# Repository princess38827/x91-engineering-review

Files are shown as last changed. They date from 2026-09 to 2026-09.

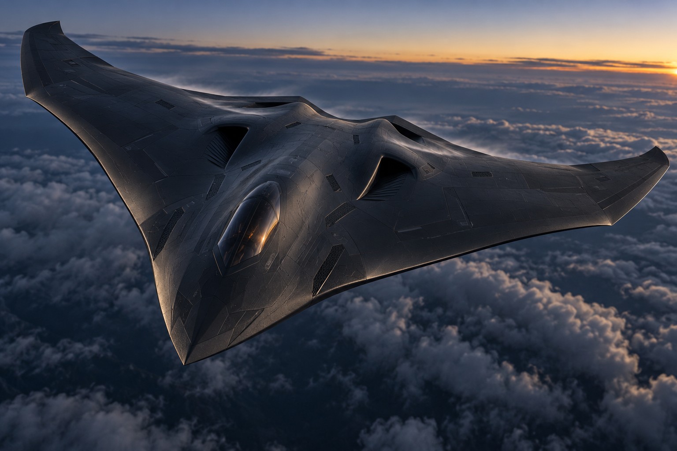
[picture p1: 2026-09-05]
assets/x91-concept-reference.jpg

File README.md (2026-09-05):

# X-91 Engineering Review Portal

Static Vercel portal and complete source package for the X-91 civilian, non-weaponized flight demonstrator approval candidate.

## Status

This repository is **not a fabrication or flight authorization**. All flight-control approval requirements remain open until supported by measured evidence and signed by qualified reviewers.

## Local preview

```bash
python3 -m http.server 8080
```

Open `http://localhost:8080`.

## Verification

```bash
PYTHONPATH=source python3 -m unittest discover -s source/analysis -v
python3 -m json.tool source/config.json >/dev/null
```

The `source/` directory contains the complete reproducible engineering package.

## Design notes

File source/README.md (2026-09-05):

# BLACK MANTA X-91 Civilian Flight Demonstrator

Version 0.4 adds a flight-control approval candidate data pack and verification matrix. It defines restricted modes, test evidence and reviewer signatures but does not issue approval. See `FLIGHT_CONTROL_APPROVAL_DATA_PACK_v0.4.md`. Fabrication and flight remain on hold pending qualified independent review and passing test evidence.

Version 0.1 is a non-weaponized, remotely piloted electric flying-wing research aircraft. It is intended for conceptual CAD, low-order aerodynamic study, simulator development, and eventual supervised model-aircraft testing.

## Safety boundary

This project contains no targeting, tracking of people, payload release, weapon interfaces, combat logic, or autonomous engagement capability. Autonomous functions are limited to navigation, envelope protection, geofencing, return-to-home, and supervised landing research. The design is not flight-certified and must be reviewed by a qualified aeronautical engineer and operated under applicable FAA rules before fabrication or flight.

## Baseline configuration

- Wingspan: 1.40 m
- Length: 0.82 m
- Reference wing area: 0.56 m2
- Target mass: 4.0 kg
- Propulsion: two enclosed 70 mm electric ducted fans
- Control: split elevons; no vertical stabilizers
- Intended flight regime: subsonic model-aircraft research
- Target center of gravity: 24% mean aerodynamic chord
- Initial static-margin design target: 7%

## Package contents

- `config.json` - baseline dimensions, mass, atmosphere, and safety constraints
- `cad/x91_airframe.scad` - parameterized conceptual exterior model
- `analysis/x91_aero.py` - low-order lift, drag, stall, trim, static-margin, and propulsion estimates
- `analysis/test_x91_aero.py` - repeatable engineering sanity checks
- `results/` - generated plots and summary after running the analysis
- `TEST_PLAN.md` - staged simulation, bench, taxi, glide, and supervised-flight plan
- `INTERFACE.md` - fictional cockpit/ground-station information architecture
- `review/X91_Pre-Fabrication_Review_Dossier_v0.2.pdf` - preliminary five-area engineering screen and independent-review handoff
- `review/screening_calculations.json` - traceable structural and energy screening values

## Run the analysis

```bash
python3 analysis/x91_aero.py
python3 -m unittest analysis/test_x91_aero.py
```

The model intentionally uses conservative, transparent equations rather than pretending to be computational fluid dynamics. Its purpose is to expose assumptions and reject obviously unsafe configurations before higher-fidelity analysis.

## Gate to physical construction

Do not fabricate or fly from this package alone. The next technical gate requires independent review of structural loads, flutter, control authority, battery containment, EDF ingestion protection, radio failsafe behavior, and local operating rules.

Version 0.2 includes a preliminary pre-fabrication dossier. Its formal disposition is **HOLD** until missing component and structural data are supplied and an appropriately qualified independent reviewer signs the specified disposition.

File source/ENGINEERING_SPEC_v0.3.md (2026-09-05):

# X-91 civilian demonstrator - preliminary engineering specification v0.3

Status: **HOLD FOR INDEPENDENT REVIEW.** This is a traceable design recommendation, not a fabrication release, airworthiness finding, or substitute for a qualified aeronautical engineer. The aircraft remains non-weaponized and has no payload-release, targeting, or person-tracking capability.

## Frozen design intent

- 1.40 m one-piece flying wing, 0.56 m2 area, 4.0 kg target and 4.5 kg absolute design mass.
- Envelope: +3.5/-1.5 g limit, 1.5 ultimate factor, 45 m/s design-dive speed pending flutter clearance.
- Two isolated 6S EDF branches; independent receiver/servo power; manual override and geofence.
- First flights are manual, line-of-sight, speed-limited expansion only after proof, propulsion, ground-vibration and glide gates pass.

## Structure and materials

| Item | Selected baseline | Design input / acceptance |
|---|---|---|
| Main and rear spars | Two continuous Easy Composites CFT-RWM-20-17 tubes, 20 mm OD x 17 mm ID, tip-to-tip | Use E = 55 GPa and 250 MPa design allowable only provisionally. Supplier gives geometry, 139 g/m, 0/90 layup and 80 C service limit but no strength/modulus. Test three coupons from the actual batch. |
| Wing skins | 0.40 mm quasi-isotropic carbon/epoxy each face, nominal [0/+45/-45/0], over 5 mm Gurit Corecell I60 SAN foam | Core nominal density 65 kg/m3. Faces and core require batch records and coupons. The closed D-box from leading edge to rear spar carries torsion. |
| Spar/skin joints | 3M DP190 Gray, 0.20-0.30 mm controlled bondline; 40 mm minimum wrap/saddle at ribs and hard points | Use 5 MPa provisional design shear, never vendor typical strength as an allowable. Prepare, cure and witness-coupon with each bonding session. |
| Center joint | None in primary wing box | One-piece spars and skins. Equipment hatches must not sever D-box fibres. |
| Hard points | 2 mm G10 load spreaders bonded both faces at EDF, battery tray, launch and landing contacts | No point fastener through an unreinforced sandwich panel. Pot all penetrations. |

At +5.25 g ultimate, the screen predicts 231.7 N total lift and 34.1 N m root moment per side. If the spars share that moment equally, nominal tube stress is 45.4 MPa versus the provisional 250 MPa allowable (5.5 ratio before joints, holes, defects, sweep and local buckling). The calculated first half-wing bending mode is 25.3 Hz using assumed E and mass placement. Neither value closes structural or flutter requirements until correlated to test.

## Stiffness and mass control

| Station from centerline | Item | Maximum mass each side | CG tolerance |
|---:|---|---:|---:|
| 0.00-0.16 m | One 6S battery, tray and restraint | 0.72 kg | +/-5 mm spanwise |
| 0.25-0.35 m | EDF, motor, ESC, mount and duct | 0.43 kg | +/-3 mm |
| 0.25-0.63 m | Elevon, hinges, horn and servo | 0.09 kg | +/-2 mm chordwise |
| distributed | Half wing structure/wiring/finish | 0.72 kg | balance left/right within 10 g |

Acceptance targets: first bending >=22 Hz, first torsion >=35 Hz, corresponding left/right modes within 5%, and elevon trailing-edge free play at four locations <=0.25 mm. Control-surface balance changes require aeroelastic review. These gates do not by themselves prove a 45 m/s flutter boundary.

## Elevons and actuators

- Each elevon spans 35-90% semispan (0.385 m), with 22% local chord (about 68 mm average), sealed gap, three hinges, and horn near 70% span.
- KST X10 V8.0 at regulated 7.4 V: vendor rating 9.5 kgf cm and 0.12 s/60 deg; mechanical range +/-50 deg. Use a rigid 2 mm pushrod, ball links and no flexible Z-bend.
- Command limits: pitch +/-18 deg; differential roll +/-22 deg; combined command clipped to +/-22 deg; physical stop +/-25 deg; initial reflex 2 deg subject to glide trim.
- At 45 m/s, assumed hinge coefficient 0.05 predicts 0.111 N m. After 70% linkage efficiency the vendor torque gives a 5.87 ratio. Verify by load cell at minimum bus voltage and worst linkage angle; require >=2.0 torque margin without continuous stall-torque operation.

## Propulsion and battery branches

Each branch is: Spektrum SPMX46S50 6S 4000 mAh 50C Smart G2 battery -> accessible arming connector -> Littelfuse 0498100.M 100 A MIDI fuse in covered holder -> Hobbywing Skywalker 100A V2 ESC -> JP Hobby JPH6007-100 70 mm 12-blade EDF with 2250 Kv motor.

Manufacturer/retailer datum for each EDF at 22.2 V is 76.6 A, 1,725 W and 2.35 kg static thrust. The ESC is rated 100 A continuous/120 A peak on 3-6S, giving 1.31 current-rating headroom before thermal derating. The pack is 144 x 42 x 43 mm, 615 g, 10 AWG, soft-case, and vendor-rated 50C. Full-throttle duration at 75% usable energy is only 2.32 minutes; flight timing must use logged consumption.

Battery tray: 1.0 mm 6061-T6 bottom pan over a 3 mm silicone/fiberglass thermal pad, 2 mm G10 sidewalls, two independent 20 mm aramid straps per pack crossing structural frames, positive fore/aft stops, and 6 mm clearance around the pouch. Each compartment vents through a minimum 1,200 mm2 downward/aft outlet separated from EDF intake and avionics; it cannot be a sealed pressure vessel. Install fuse within 100 mm conductor length of the positive terminal. Final wire gauge, fuse curve and connector temperature require branch bench test; the fuse protects wiring against faults, not cells against every failure.

## Analysis status

- Rigid-body 6-DOF: the included state-space screen has stable assumed longitudinal and lateral modes after a 3 degree control doublet. Its derivatives are placeholders. Replace them with AVL/CFD/wind-tunnel derivatives and measured mass properties before control-law tuning.
- Modal/flutter: the included Euler-Bernoulli model estimates bending only. Conduct free-free ground-vibration testing with accelerometers and impact/shaker excitation; update an FEM to match frequencies within 5% and mode shapes by MAC >=0.90. A qualified aeroelastic analyst must demonstrate flutter speed >=1.20 times the approved maximum test speed. No flight excitation precedes that finding.

## Proof-load test

1. Use a production-representative static article in a guarded fixture. Support actual inertial-load paths; apply elliptical upward load using at least eight calibrated points per half-wing and include battery/EDF inertial loads.
2. Instrument both spar roots with strain gauges and both tips with displacement transducers. Record load, strain and deflection at >=50 Hz. Photograph bonds before and after.
3. Load 0, 25, 50, 75 and 100% of +3.5 g limit, holding each 60 s. Unload and require residual tip deflection <=1.0 mm, no audible event, crack, delamination, fastener motion or nonlinear strain.
4. Proof to 125% limit (+4.375 g, 193.1 N total aerodynamic load) for 60 s. Apply negative case separately to -1.875 g proof. Pass only with strain repeatability within 5% and no permanent set/damage.
5. On a sacrificial qualification article only, load to +5.25 g ultimate (231.7 N) for 3 s. Correlate the model and ultrasonically/tap-test critical bonds.

## Instrumented propulsion test

Use a bolted thrust stand behind a barrier, sterile inlet area, remote arming, fire-resistant battery station and emergency-cutoff observer. Measure per branch: thrust, optical RPM, voltage, current, watt-hours, battery/ESC/motor temperatures, vibration and ambient temperature at >=10 Hz (vibration >=2 kHz).

Run each branch alone, then both: 10 s at 25%, 10 s at 50%, 20 s at 75%, 10 s at 100%; cool and inspect; then 60 s at expected climb and 180 s at expected cruise. Abort on pack swelling, smoke/odor, abnormal vibration, witness-mark movement, current >90 A, any cell <3.45 V under load, battery >55 C, ESC >85 C, motor case >90 C, or thrust mismatch >10%. Acceptance requires no abort, no resonance trend, thrust/current repeatability within 5%, and connectors/fuse holders <60 C. Derive the operational throttle cap from this test.

## Independent review release gates

The reviewer signs separate structural loads, material/coupon, modal/flutter, stability/control, battery/electrical and propulsion-test findings. Fabrication remains on hold until drawings, travelers, actual mass properties, test data and nonconformances enter a controlled revision.

## Primary sources

- Easy Composites tube: https://www.easycomposites.co.uk/20mm-roll-wrapped-carbon-fibre-tube-metric
- Gurit Corecell I: https://www.gurit.com/corecell-i/
- 3M DP190: https://multimedia.3m.com/mws/media/1235570O/dp190-scotch-weld-technical-data-sheet.pdf
- Spektrum battery: https://www.spektrumrc.com/product/spektrum-accessories-22.2v-4000mah-6s-50c-smart-g2-lipo-battery-ic5/SPMX46S50.html
- Littelfuse fuse: https://www.littelfuse.com/assetdocs/midi-32v-bolt-down-series-data-sheet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
- Hobbywing ESC: https://www.hobbywing.com/en/products/skywalker-v2-series274
- JP Hobby EDF: https://motionrc.com/products/jp-hobby-70mm-12-blade-edf-4s-6s-power-system-w-2250kv-motor-jph6007-100
- KST servo: https://kstservos.com/products/x10-10-8kg-torque-servo-micro-digital-metal-gear-glider-servo-motor
- NASA GVT overview: https://ntrs.nasa.gov/api/citations/19870018222/downloads/19870018222.pdf

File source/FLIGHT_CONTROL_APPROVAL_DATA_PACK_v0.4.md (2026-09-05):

# X-91 flight-control approval data pack - candidate v0.4

## Approval statement

**Disposition: READY FOR QUALIFIED REVIEW, NOT APPROVED FOR FLIGHT.** This package defines the evidence, configuration and pass/fail gates needed for a qualified flight-controls engineer and test pilot to issue a restricted initial flight release. It does not grant regulatory authorization, airworthiness, fabrication release, or permission to operate.

Scope is a civilian, non-weaponized demonstrator. Payload release, targeting, person tracking, pursuit, combat logic and autonomous mission execution are excluded. Initial approval is limited to MANUAL, FBWA and RTL under direct visual-line-of-sight control.

## Controlled configuration

| Element | Approval baseline | Configuration control |
|---|---|---|
| Flight controller | Holybro Pixhawk 6X | Record serial number, hardware revision and installation drawing. Triple IMUs and redundant barometers do not replace installation testing. |
| Flight software | ArduPlane stable release | Reviewer freezes exact semantic version, git hash, bootloader, board target and signed parameter export. No automatic upgrades. |
| Navigation | External GNSS/compass, barometer and calibrated digital airspeed | Record models, firmware, orientation, bus and calibration reports. Internal compass is not the primary heading source. |
| Pilot command | Independent RC link with physical mode switch and immediate MANUAL selection | Demonstrate command latency, range, receiver failsafe and override with telemetry/GCS absent. |
| Power | Two independent regulated avionics inputs; propulsion BECs electrically excluded | Brownout, single-feed loss and ground-loop tests required. Servo rail sized from measured simultaneous actuator current. |
| Actuation | Two KST X10 V8.0 elevon servos at regulated 7.4 V | Independent output channels, mechanical stops +/-25 deg, command clipping +/-22 deg, measured direction and travel. |
| Propulsion | Two independently monitored EDF branches | Common throttle command; branch current/RPM comparison; any sustained mismatch >10% commands both branches idle and alerts pilot. |
| Logging | Onboard high-rate log plus independent test recorder | Parameters, firmware identity, IMU, EKF, RC, servo output, airspeed, GPS, power, current, RPM and failsafe events retained for every run. |

## Approval envelope

- Maximum gross mass: 4.50 kg; CG: 24% MAC nominal, allowable initial range 23-25% MAC after physical weighing.
- Initial airspeed envelope: 1.3 times measured stall speed through 25 m/s. Expansion above 25 m/s requires correlated GVT/flutter clearance; never exceed the lesser of the analyst-approved limit or 45 m/s.
- Bank command: +/-30 deg; pitch command: +15/-10 deg; pitch rate <=45 deg/s; roll rate <=90 deg/s.
- Wind: <=5 m/s steady, <=2 m/s gust spread; dry daylight; prepared field; no flight over people or occupied structures.
- Initial altitude: local rule-compliant, with minimum recovery height selected by test pilot and maximum geofence altitude/radius set for the site.
- Maximum flight duration: value derived from instrumented propulsion/endurance test with >=30% battery reserve on landing.

## Requirements and verification

| ID | Requirement | Verification | Pass evidence |
|---|---|---|---|
| FC-001 | Exact hardware, firmware and parameters are uniquely identified. | Inspection | Signed configuration index; SHA-256 hashes; readback matches controlled files. |
| FC-002 | Manual control remains available without GNSS, airspeed, telemetry or GCS. | HITL/ground | Correct surface/throttle response in every injected-loss case. |
| FC-003 | Any single avionics power-feed loss causes no reboot or actuator transient. | Bench | Voltage/current traces; no reset; no output step >2 deg. |
| FC-004 | Sensor installation is free of unacceptable vibration, magnetic and pressure errors. | Ground/taxi | IMU clipping zero; compass interference within reviewer limit; airspeed zero and scale checks pass. |
| FC-005 | Command limits prevent structural/envelope exceedance in FBWA. | SITL/HITL | Monte Carlo cases stay within bank, pitch, rate, speed and load limits. |
| FC-006 | RC loss produces the approved RTL sequence and reacquisition restores pilot authority predictably. | SITL/HITL/range | 20/20 repetitions pass with recorded transition times. |
| FC-007 | Geofence breach produces the approved return behavior without leaving the containment volume. | SITL/HITL | 20/20 boundary cases pass, including wind and GNSS error. |
| FC-008 | One EDF degradation/failure does not produce unrecoverable yaw/roll. | 6-DOF/HITL/tethered ground | Both-throttle cut triggers <=0.25 s after >10% verified mismatch; MANUAL remains available. |
| FC-009 | Servo authority, speed and thermal margin cover the approved envelope. | Bench/load | >=2.0 torque margin; full combined travel at minimum bus voltage; temperatures within limits. |
| FC-010 | State estimation degrades safely under sensor faults. | SITL/HITL | Bias, freeze, dropout and noise cases produce annunciation and approved fallback; no hidden AUTO continuation. |
| FC-011 | All safety-critical events and commands are reconstructable. | Log review | Independent time correlation <=20 ms; no required field missing; checksum retained. |
| FC-012 | Initial flights cannot enter autonomous mission execution. | Inspection/test | AUTO and GUIDED mission initiation inhibited in the controlled parameter set; bench attempt fails safely. |

## Model acceptance before control-law approval

The current 6-DOF derivatives are assumptions and cannot support gain approval. Replace them with:

1. Measured mass, CG and full inertia tensor for minimum and maximum flight mass.
2. Aerodynamic coefficient tables versus angle of attack, sideslip, control deflection and propulsion state, including post-stall uncertainty bounds.
3. Propulsion thrust and lag versus command, airspeed and battery voltage, including left/right mismatch.
4. Servo position, rate limit, deadband, backlash, bus-voltage dependence and load response.
5. Correlated structural modes from GVT, with flight-control sampling/filter frequencies checked against elastic modes.

The nonlinear model passes only if trim residuals are within 2% weight and 0.5 deg control, predicted static margin agrees with glide/ground evidence within 2% MAC, and measured doublet responses fall inside the model's 95% uncertainty bounds. Control gains cannot be finalized before correlation.

## SITL and HITL campaign

Use the frozen ArduPlane binary and controlled parameter file. Run nominal cases and at least 200 Monte Carlo trials per safety-critical scenario across mass, CG, aerodynamic uncertainty, wind, sensor bias, battery voltage, servo rate and propulsion mismatch.

Scenarios: takeoff/launch transient; pilot doublets; stall approach and recovery; minimum/maximum CG; 5 m/s crosswind; gusts; RC loss/recovery; GCS loss; GNSS dropout/jump; compass bias; airspeed freeze/blockage/bias; barometer drift; one power-feed loss; one servo slow/jammed at neutral/offset; one EDF 10/25/50/100% loss; fence breach at every boundary; RTL from minimum energy; CPU load and logging saturation.

Pass criteria: no departure, sustained oscillation, command reversal, geofence escape, reboot or structural-envelope exceedance; pilot override always works; required annunciation occurs; terminal states are controlled landing/approved loiter or manual recovery. Every failure is dispositioned before approval.

## Ground and restrained tests

1. Configuration audit and independent control-direction check.
2. Avionics power interruption, brownout and servo-load test while logging.
3. Vibration survey with each EDF alone and together through the full RPM range; inspect notch/filter separation from structural modes.
4. Pitot leak, zero, scale and blockage tests; compass interference test at every throttle setting.
5. RC/GCS range and antenna-orientation tests; verify failsafe timing and manual reacquisition.
6. Restrained asymmetric-thrust detection using controlled RPM/current reduction on one branch.
7. Hardware-in-loop test with the exact installed controller, receiver, sensors and servo loads.

## Restricted flight-test cards

| Card | Objective | Entry gate | Maximum task |
|---|---|---|---|
| FT-01 | Unpowered glide trim | Structural proof, CG and manual control signed | Straight glide, small pitch corrections, no automation. |
| FT-02 | Powered straight flight | Propulsion, vibration and FT-01 pass | MANUAL only, <=18 m/s, shallow turns, immediate landing. |
| FT-03 | Stabilized-mode evaluation | Correlated manual response and HITL pass | FBWA, 5 deg pitch and 15 deg bank steps. |
| FT-04 | Envelope identification | FT-03 stable and model updated | Small doublets, stall approach at safe height, <=25 m/s. |
| FT-05 | RTL demonstration | RC-loss/geofence HITL 20/20 pass | Pilot-commanded RTL with immediate MANUAL takeover available. |

Each card requires test pilot, flight-test engineer and safety observer; weather/site go-no-go; abort plan; telemetry and onboard logging; post-flight inspection; data review and written authorization before the next card.

## Approval signatures

| Role | Required finding | Name / credential / signature / date |
|---|---|---|
| Flight-controls engineer | Requirements, model correlation, gain/limit and V&V evidence acceptable | ______________________________ |
| Aeroelastic/structures reviewer | Approved control envelope is inside structural and flutter clearance | ______________________________ |
| Electrical/propulsion reviewer | Power, actuator and asymmetric-thrust protections acceptable | ______________________________ |
| Flight-test pilot | Test cards, abort criteria, handling risks and site limits accepted | ______________________________ |
| Configuration manager | Hardware/software/parameter baseline and evidence hashes complete | ______________________________ |

Approval, if granted, is limited to the identified airframe serial number, mass/CG range, firmware hash, parameter hash, hardware configuration, site and envelope. Any change affecting geometry, mass distribution, servo linkage, propulsion, sensors, flight software or parameters suspends approval pending impact review.

## References

- ArduPilot Pixhawk 6X: https://ardupilot.org/plane/docs/common-holybro-pixhawk6X.html
- ArduPilot SITL: https://ardupilot.org/dev/docs/using-sitl-for-ardupilot-testing.html
- ArduPilot airspeed sensor guidance: https://ardupilot.org/plane/docs/airspeed.html
- ArduPilot advanced failsafe configuration: https://ardupilot.org/plane/docs/advanced-failsafe-configuration.html
- ArduPilot parameter reference: https://ardupilot.org/plane/docs/parameters.html
- FAA educational/recreational operations: https://www.faa.gov/uas/educational_users
- FAA Part 107 waivers: https://www.faa.gov/uas/commercial_operators/part_107_waivers

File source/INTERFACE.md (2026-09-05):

# Fictional Cockpit and Ground-Station Interface

The interface prioritizes the operator's authority and the aircraft's recoverability.

## Primary display

- Flight mode: MANUAL, ASSISTED, RETURN, LAND
- Airspeed, altitude AGL, battery state, link quality, GPS quality
- Centered attitude display with explicit envelope limits
- Geofence distance and home direction
- Independent left/right EDF current and temperature

## Persistent safety controls

- Large MANUAL OVERRIDE control
- RETURN HOME control
- MOTOR SAFE control requiring deliberate confirmation
- Lost-link timer and currently armed recovery action
- Warning history with timestamps and acknowledgement state

## Autonomous-function boundary

Permitted functions are route following, altitude holding, envelope protection, return-to-home, and supervised landing. The interface exposes no target list, threat score, engagement control, payload release, or person-tracking view.

## Data record

Every mode transition records time, operator action, reason, software version, flight-plan checksum, and vehicle state. This provides a provenance trail suitable for safety review and incident reconstruction.

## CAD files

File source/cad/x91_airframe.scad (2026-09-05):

/*
 BLACK MANTA X-91 - civilian scale demonstrator exterior
 Conceptual visualization only; not structural or manufacturing authority.
 Units: millimeters.
*/

$fn = 64;

span = 1400;
length = 820;
body_thickness = 86;
skin_thickness = 3;
edf_diameter = 70;

module planform_2d() {
    polygon(points=[
        [ length * 0.50,    0],
        [ length * 0.28,  span * 0.22],
        [-length * 0.18,  span * 0.50],
        [-length * 0.35,  span * 0.48],
        [-length * 0.42,  span * 0.25],
        [-length * 0.30,  span * 0.08],
        [-length * 0.38,    0],
        [-length * 0.30, -span * 0.08],
        [-length * 0.42, -span * 0.25],
        [-length * 0.35, -span * 0.48],
        [-length * 0.18, -span * 0.50],
        [ length * 0.28, -span * 0.22]
    ]);
}

module blended_shell() {
    hull() {
        translate([80, 0, 0])
            linear_extrude(height=18, center=true, scale=0.98)
                planform_2d();
        translate([-70, 0, 0])
            scale([0.72, 0.40, 1])
                sphere(d=body_thickness);
        translate([80, 0, 16])
            scale([2.8, 1.5, 0.55]) sphere(d=74);
    }
}

module canopy() {
    translate([170, 0, 42])
        scale([2.0, 0.72, 0.52]) sphere(d=70);
}

module edf_duct(y) {
    translate([-65, y, 12])
        rotate([0, 90, 0])
            cylinder(h=240, d=edf_diameter, center=true);
}

module elevon_gap(y_sign=1) {
    translate([-275, y_sign * 375, 0])
        cube([260, 7, 35], center=true);
}

module x91_exterior() {
    difference() {
        union() {
            blended_shell();
            canopy();
        }
        edf_duct(145);
        edf_duct(-145);
        elevon_gap(1);
        elevon_gap(-1);
    }
}

x91_exterior();

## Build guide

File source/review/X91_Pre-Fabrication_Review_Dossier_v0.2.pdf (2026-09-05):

X-91 PRE-FABRICATION REVIEW - PRELIMINARY / NOT A CERTIFICATION | Page 1

# BLACK MANTA X-91

## Civilian Scale Flight Demonstrator

PRE-FABRICATION REVIEW DOSSIER - VERSION 0.2

## This dossier is a preliminary engineering screen and reviewer handoff. It is not an

independent review, professional engineering certification, airworthiness determination, fabrication authorization, or approval to fly.

Configuration | 1.40 m span, 4.0 kg target / 4.5 kg maximum concept mass
Propulsion | Two enclosed 70 mm electric ducted fans; 6S 6 Ah conceptual battery
Review areas | Structural loads, flutter, control authority, battery containment, EDF safety
Overall disposition | HOLD - fabrication inputs and qualified independent sign-off required

X-91 PRE-FABRICATION REVIEW - PRELIMINARY / NOT A CERTIFICATION | Page 2

# 1. Executive disposition

None of the five review areas can receive a fabrication pass from the current conceptual dataset. The aerodynamic baseline is useful for requirements definition, but it does not contain the material allowables, structural section properties, stiffness and mass distribution, control-surface geometry, actuator data, battery construction, or exact EDF/ESC specifications needed for verification.

Area | Status | Reason
Structural loads | BLOCKED | Load requirement estimated; no spar, skin, joint, or material capacity data.
Flutter | BLOCKED | No modal frequencies, torsional stiffness, hinge free-play, or mass-balance data.
Control authority | BLOCKED | No elevon dimensions, hinge moment, servo torque/speed, or 6-DOF response.
Battery containment | BLOCKED | Pack model, chemistry details, current limits, tray, venting, fuse, and restraint undefined.
EDF safety | BLOCKED | Fan/ESC models, rotor certification, duct clearances, guards, current and temperature tests undefined.

Decision: DO NOT FABRICATE FROM VERSION 0.2.

# 2. Structural-load screening

For requirements screening only, the maximum concept mass is evaluated at +3.5 g limit load with a 1.5 ultimate factor. Using a simplified spanwise lift resultant at 42% of each semispan gives the following preliminary demand. These values are not a structural capacity calculation and do not address negative-g, landing, launch, gust, concentrated EDF, battery, or control-surface loads.

Quantity | Screening value
Maximum concept mass | 4.50 kg
Positive limit load | +3.50 g
Ultimate load factor | 5.25 g
Ultimate total lift | 231.7 N
Preliminary root moment, each side | 34.1 N m

### Required closure evidence

Final mass and CG table; spar geometry and section properties; material allowables and manufacturing process; joint and fastener details; skin/core properties; EDF and battery hard-point loads; positive/negative maneuver, gust, landing and handling cases; finite-element or validated hand analysis; proof-load procedure; and acceptance criteria with no permanent deformation.

# 3. Flutter and aeroelastic screening

No flutter speed can be calculated responsibly from the current model. A flying wing with broad elevons is sensitive to torsional flexibility, hinge free-play and control-surface mass distribution. A speed cap selected without those measurements would be arbitrary.

Required closure evidence: measured wing bending and torsional stiffness; component mass distribution and inertias; elevon hinge stiffness/free-play; actuator compliance; ground-vibration or modal test; control-surface balance assessment;

X-91 PRE-FABRICATION REVIEW - PRELIMINARY / NOT A CERTIFICATION | Page 3

and an aeroelastic analysis demonstrating adequate separation between the approved flight envelope and predicted flutter boundary. Any unexplained buzz, oscillation or control reversal is an immediate stop condition.

# 4. Control-authority screening

The 7% estimated static margin is a reasonable analysis target, but stability margin alone does not prove controllability. Pitch trim, roll rate, stall recovery, asymmetric-thrust response and landing flare authority require defined elevon geometry, aerodynamic derivatives and actuator performance.

Required closure evidence: elevon span/chord and travel limits; hinge-moment estimate across the envelope; servo continuous/stall torque and speed at minimum bus voltage; linkage stiffness and backlash; control allocation and saturation logic; six-degree-of-freedom simulation; hardware-in-the-loop failsafe tests; and reduced-mass glide-article evidence before powered flight.

X-91 PRE-FABRICATION REVIEW - PRELIMINARY / NOT A CERTIFICATION | Page 4

# 5. Battery-containment screening

The conceptual 6S 6 Ah pack stores approximately 133.2 Wh nominally. The configuration does not yet identify pack construction, maximum continuous current, connector rating, fuse, restraint, impact protection, cooling or a safe vent path. Containment cannot be approved.

Required feature | Acceptance evidence
Mechanical restraint | Positive retention in all axes; no reliance on hook-and-loop material alone; reviewed crash-load path.
Electrical isolation | Insulated terminals, keyed connector, accessible arming plug and appropriately selected overcurrent protection.
Thermal protection | Temperature sensing, conservative current limit, cooling analysis and ground test at worst expected load.
Failure management | Vent path away from occupants/electronics, fire-resistant local barrier, damaged-pack quarantine procedure.
Operations | Charging outside aircraft with compatible balance charger; storage-state and preflight inspection records.

# 6. EDF safety screening

The airframe currently specifies only diameter and aggregate conceptual thrust. Rotor integrity, duct clearances, inlet access, foreign-object ingestion, ESC protection and thermal behavior are unresolved.

Hazard | Required control before powered testing
Rotor burst | Use manufacturer-rated fan/rotor; inspect and balance; document maximum RPM; provide appropriate local shielding.
Ingestion/contact | Guard accessible inlets during ground work; defined exclusion zone; restraints rated above measured static thrust.
Foreign objects | Clean duct and work area; tool and fastener accountability; intake inspection before every run.
Electrical overload | Matched motor/ESC/battery; logged current and voltage; fuse or equivalent protection; conservative software limit.
Overtemperature | Instrument motor, ESC and battery; staged-duration test; automatic abort threshold and cooldown procedure.
Asymmetric thrust | Independent shutdown logic and controllability analysis; first flight remains manually commanded and conservative.

# 7. Independent-review package required

Provide the independent reviewer with the revision-controlled CAD, final bill of materials, mass/CG table, structural substantiation, aeroelastic model and test data, control-system model, component data sheets, wiring/protection diagram, hazard analysis, operating limitations and staged test cards. The reviewer must be free to reject assumptions and request redesign or additional testing.

Independent reviewer name

Qualifications / license / relevant experience

Organization and independence statement

X-91 PRE-FABRICATION REVIEW - PRELIMINARY / NOT A CERTIFICATION | Page 5

Documents and revisions reviewed

Disposition | REJECT / REVISE AND RESUBMIT / APPROVE FOR SPECIFIED FABRICATION ONLY

Limitations and conditions

Signature and date

## Current project disposition: HOLD. This page is intentionally unsigned. No statement

elsewhere in this dossier overrides that status.

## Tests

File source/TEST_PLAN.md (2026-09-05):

# X-91 Development and Test Gates

> Version 0.3 detailed acceptance procedures are controlled by `ENGINEERING_SPEC_v0.3.md`. This file remains the high-level sequence.

Advancement requires written pass/fail evidence at every gate. A failed gate returns the aircraft to analysis; it does not permit accepting unexplained risk.

## Gate 0 - Independent design review

- Verify mass budget, center of gravity, control directions, structural load assumptions, battery containment, and EDF guards.
- Review applicable FAA recreational or experimental rules and select a legal operating site.
- Confirm the aircraft contains no payload-release or targeting capability.

## Gate 1 - Simulation

- Reproduce the low-order analysis in this package.
- Add higher-fidelity aerodynamic analysis and six-degree-of-freedom simulation.
- Demonstrate recoverability from conservative pitch, roll, and lost-link cases.
- Verify geofence and manual override in software-in-the-loop testing.

## Gate 2 - Bench article

- Build a non-flying center section for battery, EDF, cooling, radio, and flight-controller integration.
- Measure static thrust, current, temperatures, vibration, and radio failsafe behavior behind physical restraints.
- Require guarded EDF inlets and an external arming interlock.

## Gate 3 - Structural article

- Proof-load the wing and control hinges under supervision using reviewed limit loads and safety factors.
- Conduct control-surface backlash and flutter-risk review.
- Do not proceed if permanent deformation, delamination, overheating, or abnormal vibration occurs.

## Gate 4 - Unpowered validation

- Use a reduced-mass foam glide article before the powered aircraft.
- Confirm center-of-gravity range, trim direction, and benign low-speed response over an isolated approved field.

## Gate 5 - Restrained and taxi testing

- Verify thrust symmetry, steering/launch behavior, abort control, and immediate motor shutdown.
- Maintain a physical exclusion zone and trained spotter.

## Gate 6 - Supervised first flight

- Qualified remote pilot, visual observer, conservative weather, predeclared test card, and immediate abort criteria.
- Manual control only for the first flights; autonomy remains disabled until the airframe and estimator are validated.

## Gate 7 - Safety-bounded autonomy

- Enable only geofenced waypoint navigation, envelope protection, return-to-home, and supervised landing.
- Human command authority and immediate manual override remain active.
- No operation over people, public roads, or unapproved property.

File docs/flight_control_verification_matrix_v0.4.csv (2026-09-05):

requirement_id | requirement | method | status | evidence_file | reviewer | review_date | notes
FC-001 | Unique hardware firmware and parameter identity | Inspection | OPEN
FC-002 | Manual control independent of navigation and telemetry | HITL and ground | OPEN
FC-003 | Single avionics power feed loss tolerated | Bench | OPEN
FC-004 | Sensor installation interference acceptable | Ground and taxi | OPEN
FC-005 | FBWA envelope protection | SITL and HITL | OPEN
FC-006 | RC-loss and recovery behavior | SITL HITL and range | OPEN
FC-007 | Geofence containment | SITL and HITL | OPEN
FC-008 | Asymmetric-thrust response | 6DOF HITL and restrained ground | OPEN
FC-009 | Servo authority speed and thermal margin | Bench load | OPEN
FC-010 | Safe state-estimation degradation | SITL and HITL | OPEN
FC-011 | Safety event reconstruction | Log review | OPEN
FC-012 | Autonomous mission execution inhibited | Inspection and bench | OPEN

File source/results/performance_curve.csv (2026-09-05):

speed_m_s | drag_n | power_w
12.821746912084597 | 5.251273725984013 | 67.33050268064649
13.066942316184727 | 5.19280346666594 | 67.85406335820792
13.312137720284856 | 5.142668367270028 | 68.45990955485108
13.557333124384986 | 5.100365529887766 | 69.14735454481878
13.802528528485116 | 5.065436324882158 | 69.91582938341078
14.047723932585244 | 5.037461795772797 | 70.76487262796137
14.292919336685374 | 5.0160586111209895 | 71.69412111683837
14.538114740785502 | 5.000875490244308 | 72.7033016815537
14.783310144885633 | 4.991590040419886 | 73.79222368364938
15.028505548985763 | 4.987905952313587 | 74.96077228216386
15.273700953085891 | 4.98955050800461 | 76.20890234958021
15.518896357186021 | 4.996272362411363 | 77.5366329645349
15.76409176128615 | 5.007839564367625 | 78.9440424184905
16.00928716538628 | 5.024037788214002 | 80.4312636812701
16.25448256948641 | 5.044668750694718 | 81.99848027700007
16.49967797358654 | 5.06954879129603 | 83.64592252776937
16.744873377686666 | 5.098507597022394 | 85.3738641273135
16.990068781786796 | 5.131387055056709 | 87.18261901138386
17.235264185886926 | 5.168040218855113 | 89.07253849525677
17.480459589987056 | 5.208330375037916 | 91.04400865215243
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

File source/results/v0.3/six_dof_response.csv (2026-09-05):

time_s | u_m_s | w_m_s | q_rad_s | theta_rad | v_m_s | p_rad_s | r_rad_s | phi_rad
0.0 | 0.0 | 0.0 | 0.0 | 0.0 | 0.0 | 0.0 | 0.0 | 0.0
0.01 | 0.0 | 0.0 | 0.0 | 0.0 | 0.0 | 0.0 | 0.0 | 0.0
0.02 | 0.0 | 0.0 | 0.0 | 0.0 | 0.0 | 0.0 | 0.0 | 0.0
0.03 | 0.0 | 0.0 | 0.0 | 0.0 | 0.0 | 0.0 | 0.0 | 0.0
0.04 | 0.0 | 0.0 | 0.0 | 0.0 | 0.0 | 0.0 | 0.0 | 0.0
0.05 | 0.0 | 0.0 | 0.0 | 0.0 | 0.0 | 0.0 | 0.0 | 0.0
0.06 | 0.0 | 0.0 | 0.0 | 0.0 | 0.0 | 0.0 | 0.0 | 0.0
0.07 | 0.0 | 0.0 | 0.0 | 0.0 | 0.0 | 0.0 | 0.0 | 0.0
0.08 | 0.0 | 0.0 | 0.0 | 0.0 | 0.0 | 0.0 | 0.0 | 0.0
0.09 | 0.0 | 0.0 | 0.0 | 0.0 | 0.0 | 0.0 | 0.0 | 0.0
0.1 | 0.0 | 0.0 | 0.0 | 0.0 | 0.0 | 0.0 | 0.0 | 0.0
0.11 | 0.0 | 0.0 | 0.0 | 0.0 | 0.0 | 0.0 | 0.0 | 0.0
0.12 | 0.0 | 0.0 | 0.0 | 0.0 | 0.0 | 0.0 | 0.0 | 0.0
0.13 | 0.0 | 0.0 | 0.0 | 0.0 | 0.0 | 0.0 | 0.0 | 0.0
0.14 | 0.0 | 0.0 | 0.0 | 0.0 | 0.0 | 0.0 | 0.0 | 0.0
0.15 | 0.0 | 0.0 | 0.0 | 0.0 | 0.0 | 0.0 | 0.0 | 0.0
0.16 | 0.0 | 0.0 | 0.0 | 0.0 | 0.0 | 0.0 | 0.0 | 0.0
0.17 | 0.0 | 0.0 | 0.0 | 0.0 | 0.0 | 0.0 | 0.0 | 0.0
0.18 | 0.0 | 0.0 | 0.0 | 0.0 | 0.0 | 0.0 | 0.0 | 0.0
0.19 | 0.0 | 0.0 | 0.0 | 0.0 | 0.0 | 0.0 | 0.0 | 0.0
0.2 | 0.0 | 0.0 | 0.0 | 0.0 | 0.0 | 0.0 | 0.0 | 0.0
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
